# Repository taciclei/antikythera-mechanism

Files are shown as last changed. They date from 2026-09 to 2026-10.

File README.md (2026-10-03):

# Antikythera Mechanism: a functional, verified 3D reconstruction

**English** · [Français](README.fr.md) · [Español](README.es.md) · [Deutsch](README.de.md) · [Italiano](README.it.md) · [Português](README.pt.md) · [Ελληνικά](README.el.md) · [中文](README.zh.md) · [日本語](README.ja.md)



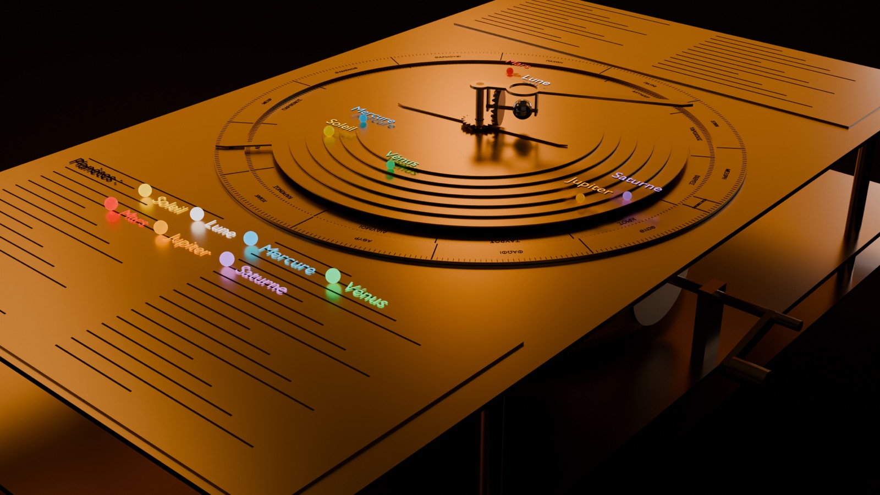
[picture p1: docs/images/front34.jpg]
The reconstructed mechanism, front three-quarter view


https://github.com/user-attachments/assets/c810d3ee-ecfa-46e3-b11d-f919c3ae2cd9

https://github.com/user-attachments/assets/40b1f61b-5fb0-4b54-bd1c-1ba1f423a424

The Antikythera Mechanism is a hand-cranked bronze astronomical calculator built in Greece in the 2nd or 1st century BC and recovered from a shipwreck in 1901. It is the oldest known complex geared machine. This repository contains a complete 3D reconstruction of it in **Blender 5.2**:

- all **69 gears** have their real tooth counts;
- the teeth are conjugate involute teeth, so every pair meshes and actually works;
- every gear train has been **checked in exact fractions** against the astronomical cycle it models;
- the parts have been **checked for collisions** over the whole range of motion.

The whole build was produced in a single pass by Claude Opus 5.5 from one self-contained master prompt ([`PROMPT_OPUS.md`](PROMPT_OPUS.md)), then verified independently.

## Two machines in this repository

| | v1: historical reconstruction | v2: Anticythère 2.0 |
|---|---|---|
| What it is | The ancient machine, as reconstructed by Freeth et al. 2021 | A modern evolution computed with 2026 astronomy |
| Where | Everything at the root of this repository | The [`v2/`](v2/README.md) folder |
| Status | Finished and verified; frozen at the [`v1-historique`](https://github.com/taciclei/antikythera-mechanism/releases/tag/v1-historique) tag | Design study in progress |
| Historical? | Yes; hypothetical parts are marked | **No**: it is an evolution, not a reconstruction |

The rest of this README describes v1.

## Highlights

- **69 gears**, tagged by how certain they are:
  - 30 **surviving**, physically present in the fragments (CT scans);
  - 7 **reconstructed**, from strong evidence;
  - 32 **hypothetical**, from the model of Freeth et al. 2021.

  Each status has its own Blender collection, so each group can be hidden or shown.
- **Exact mathematics.** 1 turn of the main wheel b1 is 1 year. The mechanism has exactly **one degree of freedom** (the crank), and all 22 targets match exactly as fractions (sample below).

  | Output | Exact rate (turns/year) | Cycle |
  |---|---|---|
  | Moon (mean) | 254/19 | 254 sidereal months in 19 years |
  | Metonic dial | −5/19 | 5 turns = 19 years = 235 lunar months |
  | Saros dial | −940/4237 | 4 turns = 223 lunar months |
  | Lunar nodes (Dragon Hand) | −5/93 | 18.6 years, backwards |
  | Venus | 289/462 relative to b1 | 289 synodic periods in 462 years |
- **Formally proved in Lean 4.** [`lean/`](lean/README.md) contains 193 theorems, checked by Lean's kernel with Mathlib, with no `sorry`:
  - the mean-rate kinematics has exactly **one degree of freedom**, and every rate follows from the tooth counts;
  - the 22 targets hold, and so do the Metonic, Saros, Exeligmos, Callippic and Olympiad cycles and the planetary period relations;
  - the 37 centre distances are correct to within 10⁻⁶ mm;
  - the pin-and-slots keep their mean rates, and the lunar anomaly amplitude lies between 6.579° and 6.581°.

  Mutation tests show that Lean rejects a wrong tooth count, a wrong target or a misplaced axis.
- **It works mechanically.**
  - Centre distances are exact to 10⁻⁶ mm, and every contact ratio is ≥ 1.2.
  - There is **0 interpenetration** on thousands of 3D (BVH) samples: every mesh over a tooth pitch, every pin-and-slot cycle, and 168 pairs of parts at 240 crank positions.
- **The Moon speeds up and slows down with round gears**, not oval ones. A pin-and-slot on the rotating e3 turntable reproduces Hipparchus' lunar anomaly (±6.58°).
- **Planets move backwards at the right time.** Mars, Jupiter and Saturn go retrograde at opposition (180° ± 0.03°), and Mercury and Venus stay within their maximum elongations.
- **One crank drives everything.** All motion comes from `AM_Controller["crank"]` in years, through simple-expression drivers, so the file animates without enabling Python scripts.
- **Readable display.** Each of the seven ancient "planets" has its own colour and a label that follows it (Sun, Moon, Mercury, Venus, Mars, Jupiter, Saturn), plus a legend.
- **Museum lighting.** The scene has a dark cyclorama backdrop and warm softboxes, rendered with AgX colour. This setup was chosen from three designs rendered side by side.
- **Exploded view.** Move `AM_Controller["explode"]` from 0 to 1 and every part slides along the stacking axis.
- **3D printing.** One STL per part plus a full 3MF, in three profiles: resin ×1, resin ×1.5 and FDM ×2.

| Front dial | Back dials |
|---|---|
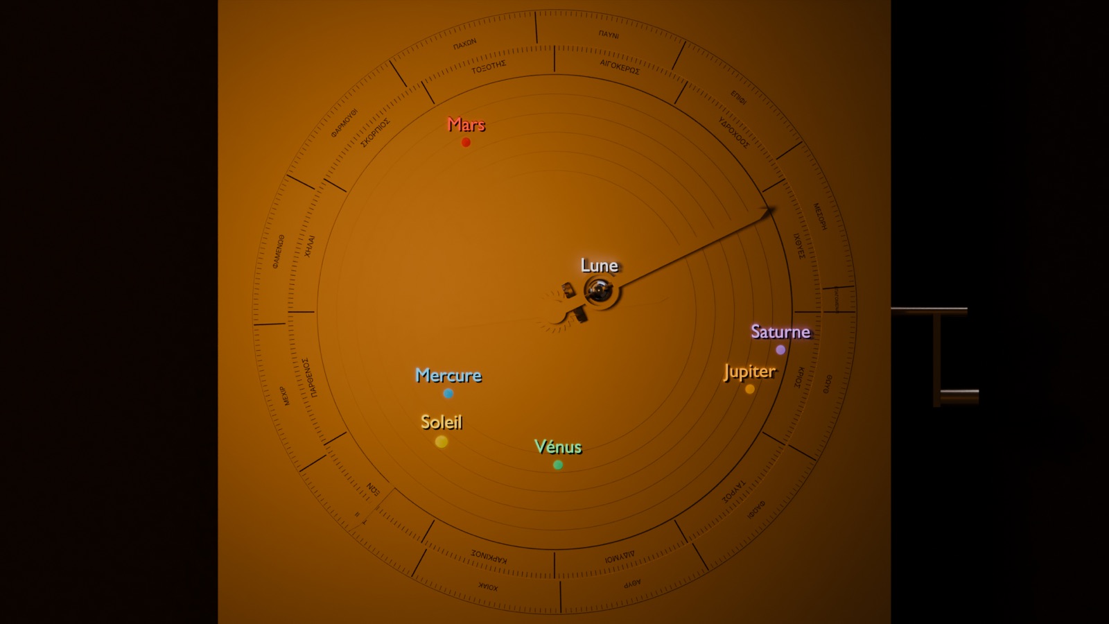
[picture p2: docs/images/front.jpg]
Front dial with coloured, labelled planets
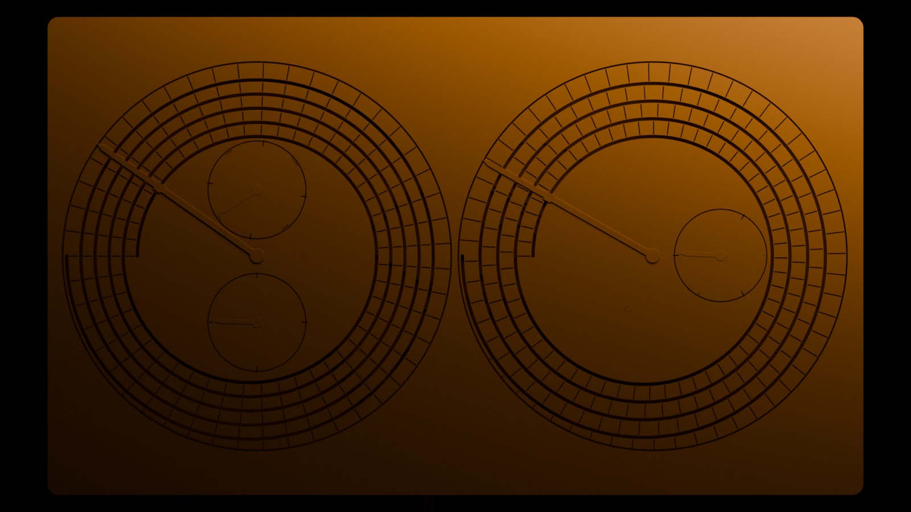
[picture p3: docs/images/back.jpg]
Metonic and Saros spirals
|  |  |

| Exploded view | Inside, opened |
|---|---|
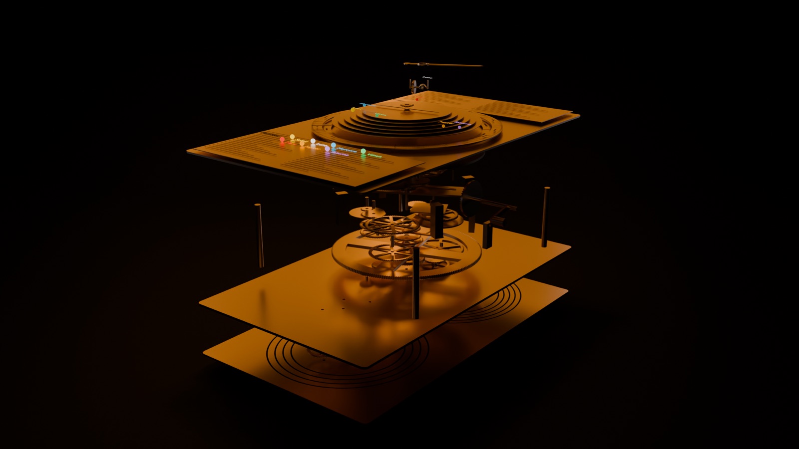
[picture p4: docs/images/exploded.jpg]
Exploded still
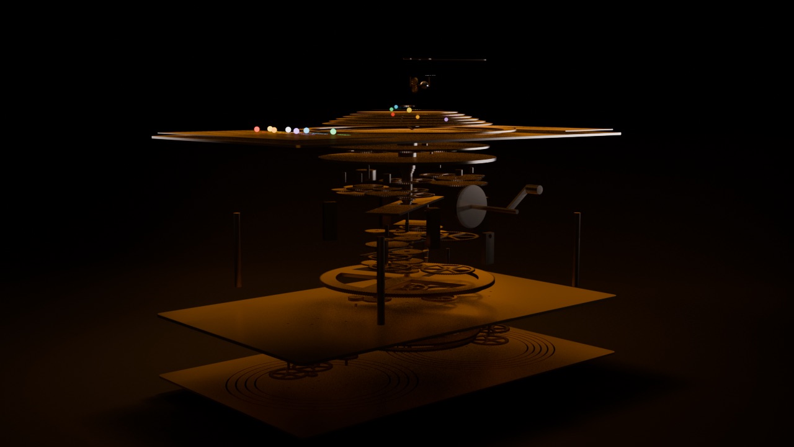
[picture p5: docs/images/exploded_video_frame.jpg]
Frame of the exploded video
|  |  |

## Videos

- [`antikythera.mp4`](build/out/renders/antikythera.mp4): 20 s. The crank turns 4 years, and the planets, Moon and back dials all move.
- [`antikythera_eclate.mp4`](build/out/renders/antikythera_eclate.mp4): 15 s exploded view. The mechanism opens layer by layer while the gears keep turning, then closes again.

Planets that sometimes move **backwards** in the videos are not a bug. This is the **retrograde motion** seen from Earth, and the mechanism was built to show it. The Dragon Hand (the lunar nodes) always turns backwards.

## Learn to read the machine

- **Explainer film** (in French, 2 min 40 s): [*Le ciel dans une boîte : comment lire la machine d'Anticythère*](https://youtu.be/eXvYkouJy_w). Seven chapters take you from the wreck to reading every dial:
  - the crank is time;
  - the Sun, the Moon and its phase on the front;
  - the planets (hypothesis) and their retrograde motion;
  - the 19-year calendar and the Games on the back;
  - how to predict an eclipse;
  - an honest answer about navigation: it was not a navigation instrument, but its star calendar marked the sailing season.
- **Interactive page**: [*Lire la machine*](https://taciclei.github.io/antikythera-mechanism/lire/). Set any date, turn the crank and read every pointer in plain French. It also finds the next full moon, the next eclipse *according to the machine* and the next Games. Calibrated on the real sky at J2000, the machine announces the total solar eclipses of 12 August 2026 and 2 August 2027 to within a few hours.
- **Behind both**: [`tools/explainer/`](tools/explainer/README.md).
  - An astronomy engine that matches the Blender drivers to 6·10⁻⁷ rad.
  - Eclipse glyphs **computed by our model**; they are not copied from the original dial.
  - The film pipeline: timeline tied to the words of the narration, shots, 2D diagrams, compositing.
- **The film's French voice-over** was generated locally with Mistral's Voxtral TTS. Its weights are licensed CC BY-NC 4.0, so the film is shared for non-commercial use.

## Quick start

1. Install **Blender 5.2** or later.
2. Open [`build/out/am.blend`](build/out/am.blend) and press **Space** to play the animation.
3. Select `AM_Controller` and change its custom properties:
   - `crank`: years; 1 is one turn of b1;
   - `explode`: 0 to 1;
   - `patina`: 0 is new bronze, 1 is museum patina.
4. Use the Outliner to hide collections:
   - `AM_CASE` and `AM_DIALS` to see the gearing;
   - `AM_HYPOTHETICAL` to keep only what is attested;
   - `AM_LABELS` to remove the labels;
   - `AM_STAGE` to remove the lighting set.
5. Click any part to read its custom properties: `status`, `role`, `teeth`, `module` and `sources`.

### Re-run the verification

Use the Python bundled with Blender. The paths below are for macOS; adapt them on other systems.

```sh
PY=/Applications/Blender.app/Contents/Resources/5.2/python/bin/python3.13
BL=/Applications/Blender.app/Contents/MacOS/Blender

$PY tools/validate_spec.py          # exact linear solve (1 DOF, 22 targets), centre distances, collision screening
$PY tools/check_kinematics.py       # pin-and-slot laws, followers, elongations, retrogrades, solar apogee
cd build && $PY -m unittest discover -s tests && $PY -m am.verify --stage all && cd ..
$BL -b build/out/am.blend --python-exit-code 1 -P tools/crosscheck_blend.py   # Blender rotations vs an independent solver
```

[`build/README.md`](build/README.md) lists every build, check, export and render step, with one command per step.

### Check the formal proofs (Lean 4)

Install [elan](https://lean-lang.org/install) once, then:

```sh
cd lean
lake exe cache get    # download the compiled Mathlib (about 5 GB)
lake build            # check every proof; warnings are errors, so success means no sorry
cd ..
python3 tools/lean_mutation_test.py   # Lean must reject 9 deliberately wrong mechanisms
```

[`lean/README.md`](lean/README.md) lists what is proved, module by module, and what is not.

### Rebuild everything from the master prompt

In an **empty** folder, with [Claude Code](https://claude.com/claude-code):

```sh
claude -p --model 'claude-opus-5-5[1m]' --effort xhigh --permission-mode acceptEdits \
  --allowedTools Bash Read Write Edit Glob Grep < PROMPT_OPUS.md
```

- [`prompts/PROMPT_OPUS_v1_validated.md`](prompts/PROMPT_OPUS_v1_validated.md) is the exact version that produced this build in one pass (89 min).
- [`PROMPT_OPUS.md`](PROMPT_OPUS.md) is v1.3. v1.2 added the planet colours and labels, the museum staging, the explode slider and the exploded video; v1.3 replaces the Olympiad (Games) dial labels with the historical pairs of festivals, two per year. All of these were added to this build afterwards with the scripts in `tools/`, and v1.3 has not yet been rerun from scratch.

## How it was made

1. **Research.** Parallel agents read the primary sources: Freeth et al. 2006, 2008 and 2021 (with the Supplementary Information), Price 1974, Budiselic et al. 2020, Woan & Bayley 2024, Anastasiou et al. 2014, and others. The results were reconciled into one data set, then checked by a sceptic agent.
2. **Specification.** [`spec/antikythera.json`](spec/antikythera.json) is the single source of truth. It gives the teeth, module, axis position, z range and bore of every gear, and every shaft, stud, boss, pin, dial and material. It is generated by `tools/make_spec.py`, which fixes 22 geometric impossibilities in the published data (for example, b2 cannot mesh with both c1 and l1 at the published distances). Every centre distance is solved exactly.
3. **Independent checks.** `tools/validate_spec.py` and `tools/check_kinematics.py` share no code with the generator, and mutation tests confirm they catch injected errors.
4. **Crown teeth by envelope.** `tools/crown_envelope.py` computes the contrate teeth of a1 and q1 as the region the mating teeth never sweep. `tools/test_crowns_blender.py` then checks them with BVH in Blender.
5. **Adversarial reviews.** Two rounds of independent reviewers covered data, the Blender API tested live, executability and geometry, and found 5 blockers and about 60 other issues. All of them are fixed.
6. **One-pass build** by a fresh Opus 5.5 session from the prompt alone: 131 turns, about 5,000 lines of code, and all acceptance criteria green.
7. **Independent verification** of the result: tests, exact checks, the full BVH check, and a cross-check of every body in `am.blend` against the independent solver (7·10⁻⁷ rad).
8. **Formal proofs.** `tools/make_lean.py` translates the spec into Lean 4. The kinematics, targets and centre distances are proved from it. Hand-written modules add the pin-and-slot analysis and the astronomy, and adversarial reviewers and mutation tests checked that each statement says what it claims.

## Repository layout

```
PROMPT_OPUS.md            master prompt (v1.3), self-contained; embeds the full JSON spec + SHA-256
prompts/                  the prompt version validated by the one-pass build (v1)
spec/antikythera.json     single source of truth (gears, axes, shafts, trains, dials, staging, video)
research/                 raw multi-agent research results with source URLs
tools/                    spec generator, validators, crown envelopes, Lean generator, annotation/staging/explode/render scripts
tools/explainer/          astronomy engine, eclipse glyphs, diagrams, inserts and the explainer-film pipeline
lean/                     Lean 4 + Mathlib proofs: kinematics, targets, centre distances, pin-and-slot, astronomy
build/                    the project generated by the one-pass build (am/, blender_scripts/, tests/, README)
build/out/                am.blend, verification report (report.md/html), checks, print files, renders, videos
docs/                     dossier (HTML), images and the interactive page docs/lire/ (GitHub Pages)
```

## Honest limits

- The planetary trains, the lunar nodes and the true Sun follow the **hypothetical** model of Freeth et al. 2021. A working animation does not prove how the original was built.
- Some quantities are not published. For these the spec uses documented defaults, listed in `spec/antikythera.json` → `unresolved_defaults`:
  - axis angles on the rear plate;
  - cosmos ring radii;
  - starting phases (the epoch is uncalibrated).
- The Lean proofs cover the mean-rate kinematics, the targets, the centre distances and the pin-and-slot and follower laws. Contact ratio, face overlap, undercut and collisions are checked by the Python tools and in Blender, not in Lean.
- The teeth are conjugate involutes (a 30° rack, which is the ancient equilateral-triangle tooth), not the hand-filed triangles of the original.
- Planet colours are for readability only; they are not historical.

## Main sources

- T. Freeth et al., "A Model of the Cosmos in the ancient Greek Antikythera Mechanism", *Scientific Reports* 11, 5821 (2021), with its Supplementary Information.
- T. Freeth et al., "Decoding the ancient Greek astronomical calculator known as the Antikythera Mechanism", *Nature* 444, 587 (2006).
- T. Freeth, A. Jones, J. Steele, Y. Bitsakis, "Calendars with Olympiad display and eclipse prediction on the Antikythera Mechanism", *Nature* 454, 614 (2008).
- T. Freeth & A. Jones, "The Cosmos in the Antikythera Mechanism", ISAW Papers 4 (2012).
- D. de Solla Price, *Gears from the Greeks* (1974).
- C. Budiselic et al. (2020); G. Woan & J. Bayley (2024): calendar ring hole count.
- M. Anastasiou et al. (2014): the back-dial spirals.

The full list with URLs is in `spec/antikythera.json` → `sources`.

## Licence

- **Code**: MIT ([`LICENSE`](LICENSE)).
- **Renders, videos, 3D model, print files and texts**: CC BY 4.0 ([`LICENSE-MEDIA.md`](LICENSE-MEDIA.md)).
- **Explainer film**: its voice-over was generated with Voxtral TTS (weights CC BY-NC 4.0), so the film is for non-commercial use.
- **Scholarly data**: please cite the works above.

---

Built with [Claude Code](https://claude.com/claude-code) (Claude Opus 5 / 5.5) for taciclei.

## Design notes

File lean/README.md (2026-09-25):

# Formal proofs in Lean 4

This folder is a [Lean 4](https://lean-lang.org) project, built on [Mathlib](https://github.com/leanprover-community/mathlib4). Its theorems about the reconstructed Antikythera Mechanism are checked by Lean's kernel. A successful `lake build` means all of the following:

- every theorem is fully proved: warnings are errors, so no `sorry` gets through;
- no theorem uses an axiom beyond Lean's three standard ones (`propext`, `Classical.choice`, `Quot.sound`), which `Antikythera/Audit.lean` checks for every declaration;
- the files generated from the spec are exactly what `tools/make_lean.py` produces. The GitHub workflow regenerates them and compares.

## What is proved

| Module | Content | Theorems |
|---|---|---|
| `Kinematics.lean` (generated) | One equation per gear contact, taken from the tooth counts: 37 Willis equations, 2 crown pairs, 4 pin-and-slots and 3 followers. See the list below the table. | 5 |
| `Targets.lean` (generated) | The spec's 22 astronomical targets, derived from the tooth counts alone. `target_b` is the normalisation, 1 turn of b1 per year. | 22 |
| `Geometry.lean` (generated) | For all 37 external meshes: equal modules, and a centre distance equal to m(z₁ + z₂)/2 within 10⁻⁶ mm. | 37 |
| `PinSlot.lean` | The nonlinear couplings. See the list below the table. | 71 |
| `Astronomy.lean` | The cycles and the precision. See the list below the table. | 58 |
| `Audit.lean` | Fails the build if any declaration depends on `sorryAx` or on a non-standard axiom. | — |

**`Kinematics.lean`** proves four results:
- `determined` and `determined_by_crank`: the crank fixes every mean rate;
- `consistent`: the equations have a solution for every crank speed;
- `moves`: the mechanism can turn;
- `one_dof`: the admissible mean-rate vectors form exactly one line, so the mechanism has **one degree of freedom**.

**`PinSlot.lean`** covers the nonlinear couplings:
- the spec's `atan2` laws for the four pin-and-slots and the three followers;
- the exact maximal deviation `arcsin(e/r)`;
- the smooth, strictly monotone slot motion;
- mean rates unchanged by a bounded lag, which formally justifies the linear fields of `Kinematics`;
- the lunar anomaly amplitude: `6.579° < arcsin(1.1/9.6) < 6.581°`;
- the amplitudes for Saturn, Jupiter, Mars, Mercury, Venus and the true Sun.

**`Astronomy.lean`** covers the cycles and the precision:
- sidereal month 254/19 and Metonic cycle (19 years = 235 synodic months);
- the Saros (223 months = 4 turns), Exeligmos, Callippic (940 months = 76 years) and Olympiad dials;
- lunar anomaly and apsides, and the nodes (Dragon Hand);
- the planetary period relations, where sidereal = solar − synodic;
- the precision in days against modern values, with 1 year = 365.2422 days. For example, the gear-implied sidereal month is within 0.0005 days of 27.321661.

Total: **193 theorems** in about 2,300 lines.

## Scope and limits

- The kinematic theorems are about **mean rates**. The instantaneous nonlinear motion of the pin-and-slots and followers is treated in `PinSlot.lean`.
- The **planetary gearing, the Dragon Hand and the true Sun** follow the hypothetical model of Freeth et al. (2021). Lean proves what that model computes, not that the ancient mechanism was built that way.
- **Not covered by Lean**: contact ratio, face overlap, undercut, crown-gear geometry and collisions. These are checked by `tools/validate_spec.py`, `tools/check_kinematics.py` and the BVH tests in Blender.

## Check it yourself

```sh
# once: install elan (the Lean toolchain manager), see https://lean-lang.org/install
cd lean
lake exe cache get    # download the compiled Mathlib (about 5 GB)
lake build            # check every proof (about 2 minutes)
cd ..
python3 tools/make_lean.py            # regenerate Kinematics / Targets / Geometry from the spec
python3 tools/lean_mutation_test.py   # Lean must reject 9 deliberately wrong mechanisms
```

The mutation test does two kinds of change:
- **In the Lean files**: a tooth count, the sign of a Willis equation, a carrier, a rate, a target value, or an axis moved by 10⁻⁵ mm.
- **In the spec, end to end**: one tooth count on the Metonic train and one on the Olympiad train.

Every mutant must fail to compile. The unmutated control must compile.

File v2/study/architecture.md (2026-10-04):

# Anticythère 2.0 — Architecture de la machine

> ⚠️ **Ce n'est pas une reconstruction historique.** C'est l'architecture d'une machine moderne, dans l'esprit
> d'Anticythère : une boîte, une manivelle, des cadrans. La v1 historique reste à la racine du dépôt.

Ce document dit **où va chaque pièce** et **comment les mouvements circulent** dans la machine. Il est produit par
`v2/tools/architecture.py`. Le script lit `spec/trains.json` et `research/calc/`, place les trains d'engrenages roue
par roue, puis vérifie qu'aucune pièce n'en heurte une autre. Les choix de conception sont dans `tools/arch_layout.py`,
`arch_routes.py` et `arch_faces.py` ; le résultat complet est dans `spec/architecture.json`.

**Version 4.** L'architecture a été relue trois fois par des revues adversariales indépendantes :
- `study/review.md` sur la version 1 ;
- `study/review2.md` sur la version 2 ;
- `study/review3.md` sur la version 3.

Chaque défaut trouvé a été corrigé ; le § 1 dit lesquels et comment.

## 0. L'essentiel

- **Une caisse de 470 × 360 × 391 mm** (largeur × hauteur × profondeur), plus l'orrery d'environ
  70 mm sur le couvercle. Masse estimée : **24,2 kg** en laiton, **20,7 kg**
  avec des platines intérieures en aluminium.
- **Trois faces** : devant le ciel vu de la Terre, derrière le calendrier et les éclipses, dessus le système solaire.
- **Cinq étages**, sept **tours planétaires** et un **bloc de la Lune**.
- **Environ 511 roues dentées**, détaillées au § 7.
- **Vérifié** :
  - 379 pièces modélisées en 3D (cylindres et tringles, avec leur cote z) ;
  - **0 collision** ;
  - 13 trains placés roue par roue ;
  - les 70 arbres de `trains.json` ont tous une place (13
    d'entre eux roue par roue, les autres dans des blocs) ;
  - faces et couvercle conformes.

## 1. Ce qui a changé après les revues

### 1.1 Première revue (version 1 → version 2)

| Défaut relevé (`review.md`) | Réponse de la version 2 |
|---|---|
| B1 · les copies de l'UAK Terre n'avaient pas d'entrée Y | Le bus arrive **sur l'axe** de la tour, sur un tube Y. Un couple 1:1 (ou un couple à pignon fou) reprend Y vers l'entrée du train. Le tube Y monte jusqu'à la copie de l'UAK Terre. |
| B2 · train J → Y : la roue de 144 traversait l'arbre Y | Ordre des couples inversé (10:83, 19:144, 31:180) ; la roue de 180 est sur Y. |
| B3 · pignons du moyeu Y4 superposés | Pignons modélisés ; deux couronnes Y4 sur deux couches (T1, T2). |
| B4 · roues du carrousel percées | Roues de 64 modélisées ; pas régulier de 40° ; tringles d'arrivée vérifiées avec le carrousel. |
| B5 · boîte de Laplace trop petite | Rayon calculé depuis les trains (r ≥ 75,1 mm, plus 4 mm) ; trois trains empilés de 10 mm. |
| I1 · mauvais arbre de précession au bloc du temps | Le bloc reçoit l'arbre de la roue de 131 et le ramène au rapport de l'anneau par son propre couple 15:179. |
| I2 · sens de rotation absent | Tableau des sens (§ 8) : chaque chaîne a un renvoi conique réglable ou un pignon fou. |
| I3 · « jeu nul en marche avant » faux | Faux en effet : onze sorties s'inversent seules. Roues anti-jeu à ciseaux exigées en aval des suiveurs (§ 9). |
| I4 · entrées manquantes (temps, Lune, bras de Lune) | Tringles J et Y vers le bloc du temps, Y vers le bloc Lune, 11ᵉ tringle (Lune) vers le couvercle. |
| I5 · arbres non prolongés | Tout arbre de train va de la platine à un pont et traverse tous les plans de son étage. |
| I6 · couches de tringles trop minces | Coniques m 0,4 (Ø 10,4 mm) et couches de 15 mm. |
| I7 · liens trop larges, interfaces cachées | Liens pièce à pièce seulement ; interfaces listées avec leur profondeur (§ 6). |
| I8 · prise héliocentrique | Couple de prise vers un arbre décalé, puis conique ; palier excentrique du suiveur F décrit (§ 10). |
| I9 · roues oubliées | Les 71 roues internes sont comptées, plus tous les nouveaux renvois. |
| I10 · pignons fous non placés | Placés (Mercure, nœud), dans le couple que choisit la recherche. |
| M1–M10 | Corrigés dans le texte : pile Ø 18,4 mm, jeu recalculé, anneau tropique, couvercle, sens des cadrans arrière, masse sans options. |

Trois choix nouveaux sont apparus pendant la reprise :
- **Neptune et Uranus échangent leurs tours.** Neptune est passée au centre de la rangée du bas.
- **Le couple 10:131 de la précession** est sous la platine P4. L'arbre L de Neptune y descend.
- **Le train du périgée** est à l'étage 4. Son arbre de sortie descend dans le bloc de la Lune.

**Deux couples changent de module ; leurs rapports restent exacts :**
- Neptune, 11:147 en m 0,55 ;
- Jupiter, 10:26 en m 0,7.

Comme dans la v1, c'est la géométrie qui commande ici, pas le rapport.

### 1.2 Seconde revue (version 2 → version 3)

| Défaut relevé (`review2.md`) | Réponse de la version 3 |
|---|---|
| N1 · dans 4 tours, la reprise directe inversait le sens de la planète | Toutes les reprises passent par un **pignon fou** (24 → fou → 24), qui garde le sens. Le fou tourne sur un **tenon porté par le pont** : son arbre ne descend pas jusqu'à la roue finale, ce qui place aussi Vénus et Neptune. |
| N2 · les couples d'entrée du bloc Lune changeaient les rapports | Couples 1:1 dédiés : 100:100 (entraxe 50) pour L et Ω, 72:72 (entraxe 36) pour ϖ. |
| N3 · l'arbre de précession n'atteignait pas le bloc du temps | Coq de 2 mm sous le couple 10:131, puis le plan du couple, puis la tringle au-dessus. Un arbre descend dans le bloc, en un point libre choisi par la recherche. |
| N4 · la bague du suiveur F ne tenait pas avec la prise à 12 mm | La roue de F (46 dents, r 12) tourne sur la bague excentrique ; sa partenaire est à 23 mm. Jupiter, Saturne et Mercure prennent du côté −x. |
| N5 · la hauteur des blocs n'était pas vérifiée | Budget de plans par bloc, vérifié (§ 4). Étage 5 : deux demi-niveaux de 30 mm. Pile avant et boîte de Laplace : 51 mm. |
| N6 · `prec_avant` : tringle de 8 mm | Remplacée par un arbre droit jusqu'au pignon de l'anneau. |
| N7 · arbres de précession sans palier bas | Coq en bas de la couche T2 (N3). |
| N8 · ciseaux sur des coniques de Ø 10 | Coniques précontraintes par ressort axial. Les 9 couples 64:64 ont des ciseaux, et leurs 9 demi-roues sont comptées. |
| N9 · liens par préfixe de nom | Liens par identifiant exact. Seules les parties d'un même axe de tour répondent à son nom. Contrôle strict au § 6. |
| N10 · comptes et interfaces | Roues recomptées ; interfaces complétées (arrivée de Y au bloc Lune). |

### 1.3 Troisième revue (version 3 → version 4)

| Point relevé (`review3.md`) | Réponse de la version 4 |
|---|---|
| A · les couples d'entrée 100:100 et 72:72 du bloc Lune ne trouvaient aucun plan | Entrées L, Ω, ϖ par 40 → pignon fou → 40 (même sens, rapport 1:1), **modélisées et placées** sans collision. |
| B · le budget du bloc Lune oubliait 2 différentiels et le 30:155 | Budget complet : 26 plans (78 mm). Étage 5 : deux demi-niveaux de 39 mm. Laplace : 18 plans (54 mm), pile avant de 54 mm. |
| B · différentiels « plats » contre coniques dans `trains.json` | Choix assumé : différentiels à engrenages droits, même relation, 3 plans de haut. |
| C · rien ne liait l'arbre de précession du bloc du temps à `prec_avant` | La tringle de précession finit sur l'arbre `prec_avant`, qui monte à l'anneau et descend dans le bloc. |
| Textes, compte de la copie de l'UAK Terre du bloc du temps (2 roues), équation du temps | Corrigés ; l'équation du temps est donnée avec l'écart de la copie (§ 11). |
| Roue de prise centrée sur l'axe au lieu de F | Écart de 3,7 mm au plus ; les jeux restent ≥ 3,8 mm (§ 10.3). |

**Un autre choix nouveau : λ du bloc du temps.**
- **Le problème.** La chaîne qui prenait λ sur l'UAK maîtresse (roue, pignon fou de r 30, roue) coupait trois arbres
  du bloc du temps.
- **La solution.** Le bloc a maintenant sa propre copie de l'UAK Terre, menée par Y, comme les tours et le bloc Lune.

## 2. Le principe : une base de temps, deux bus, des tours

1. **La manivelle mène l'arbre-jour J** (1 tour par jour solaire moyen). Le calendrier grégorien impose ce choix.
2. **J mène l'arbre de l'année Y** par 3 couples.
3. **Des bus de tringles distribuent J et Y**, comme les renvois qui mènent les cadrans d'une horloge de clocher :
   - au départ, une couronne de 96 dents mène des pignons de 24, et la tringle tourne 4 fois plus vite ;
   - à l'arrivée, un pignon de 24 mène une couronne de 96 ;
   - le rapport net vaut **1:1 exactement**.
4. **Chaque tour planétaire** reçoit Y sur un tube, dans son axe. Elle empile trois étages :
   - le train moyen, à l'étage 4. Un pignon fou sur tenon reprend Y du tube vers l'entrée du train (24 → fou → 24, même sens), et la roue finale revient sur l'axe, comme dans la minuterie d'une horloge ;
   - l'unité de Kepler de la planète et une copie de celle de la Terre, à l'étage 3 ;
   - le module vectoriel, à l'étage 2.
5. **Vers l'avant**, chaque sortie rejoint la pile de tubes du grand cadran par une tringle et un **carrousel** de neuf arbres, à 40° d'intervalle sur un cercle de 32 mm.

## 3. Les trois faces

### 3.1 Face avant : le ciel vu de la Terre

| Cadran | Centre (mm) | Rayon | Ce qu'il montre |
|---|---|---|---|
| Le ciel vu de la Terre | (0 ; 0) | 150 | Soleil vrai (arbre central) ; Lune vraie et boule de phase ; Mercure ; Vénus ; Mars ; Jupiter ; Saturne ; Uranus ; Neptune ; Dragon (nœuds de la Lune) |
| Horloge 24 h | (−188 ; 118) | 34 | temps solaire moyen (arbre-jour J) ; temps sidéral (gmst) |
| Jupiter et ses lunes | (−188 ; −118) | 34 | Io ; Europe ; Ganymède ; Callisto ; ligne des conjonctions ν ; lunette (barre à λ_J,géo + 90°) |
| Équation du temps (±16,5 min, ×10) | (188 ; −118) | 34 | équation du temps |
| Plaque d'époque (fixe) | (188 ; 118) | 34 | gravé : orbites figées en 2050, valable 2000–2100, date de mise à l'heure |

**Les deux anneaux du grand cadran :**
- **Constellations J2000 (fixe).** C'est le repère des étoiles.
- **Zodiaque tropique et mois grégoriens (tournant).** Il recule d'un tour en 25 772 ans : c'est la précession.

**La commande de l'anneau tropique.** L'anneau est une seule pièce qui tourne dans une feuillure de la platine-cadran.
- Ses 179 dents intérieures (m 0,8) sont à r 71,6 mm, sous les aiguilles.
- Le pignon de 15 dents qui le mène passe par un trou de la platine.
- Il n'y a donc pas de fente annulaire.

**La pile centrale.** Elle compte dix aiguilles : l'arbre du Soleil, au centre, et neuf tubes. Son diamètre est de
18,4 mm, avec un arbre de 4 mm et 1,6 mm de plus par tube.

Les tubes s'empilent de l'arrière vers l'avant. Le Dragon est le plus extérieur, la Lune la plus intérieure.

### 3.2 Face arrière : le temps et les éclipses

| Cadran | Centre (mm, repère machine) | Rayon | Ce qu'il montre |
|---|---|---|---|
| Calendrier grégorien | (−112 ; 15) | 105 | anneau des 366 dates (lu à l'index du haut) ; guichet du jour de la semaine ; cadran des années 00-99 et guichet des 400 ans ; voyant « bissextile » |
| Éclipses | (112 ; 15) | 105 | Soleil vrai ; Lune vraie ; disque des nœuds gravé en γ et en magnitudes ; index de la coulisse (γ, amplifié) ; secteur total / annulaire |
| Saros (223 lunaisons) et Exeligmos | (170 ; −128) | 40 | aiguille du Saros sur 223 cases ; petit cadran de l'Exeligmos (+0 h, +8 h, +16 h) |
| Plaque « mode d'emploi » (fixe) | (−120 ; −135) | 30 | gravé : comment lire chaque cadran, comme les inscriptions de la v1 |

**Le sens des graduations.** La face arrière se lit de dos. Un arbre qui tourne dans le sens horaire vu de face tourne
donc dans le sens anti-horaire vu de dos. Les graduations sont gravées pour le lecteur de dos :
- l'anneau des dates avance dans le sens anti-horaire vu de dos ;
- le Saros et les éclipses suivent la même règle.

### 3.3 Couvercle : le système solaire vu d'en haut

| Corps | Rayon affiché (mm) | Source de l'angle |
|---|---|---|
| Mercure | 24 | tour de Mercure (suiveur F) |
| Vénus | 38 | tour de Vénus (suiveur F) |
| Terre | 52 | UAK maîtresse |
| Mars | 66 | tour de Mars (suiveur F) |
| Jupiter | 80 | tour de Jupiter (suiveur F) |
| Saturne | 92 | tour de Saturne (suiveur F) |
| Uranus | 102 | tour d'Uranus (suiveur F) |
| Neptune | 111 | tour de Neptune (suiveur F) |

**Ce que montre le couvercle :**
- **Les angles sont exacts.** Ils viennent des mêmes arbres que les aiguilles de devant.
- **Les orbites se voient.** Chaque planète glisse dans une rainure fixe, cercle décentré ou ellipse.
- **Les bras sont à des hauteurs différentes.** Le bras de la Lune (12 mm autour de la Terre) passe au-dessus de la rainure de Mars ; Saturne, Uranus et Neptune ne sont qu'à 3,6–3,8 mm l'une de l'autre.
- **La Terre est un tellurion :** un globe de 14 mm, incliné de 23,44°, qui tourne en un jour sidéral.
- **Le bras de la Lune** est mené par la 11ᵉ tringle.
- **L'aiguille d'ombre** est décalée de γ par la coulisse d'éclipse.

**Les tringles qui montent :** onze, espacées d'au moins 14,0 mm, alors qu'il en faut
12,2 pour leurs pignons.

## 4. L'intérieur : cinq étages

| Étage | Rôle | z (mm) | Sous-étages (z) | Contenu |
|---|---|---|---|---|
| **E5** | étage du temps, du calendrier et de la Lune | 3–123 | anneau 3–9, m1 9–48, m2 48–87, ponts 87–90, T1 90–105, T2 105–123 | cal_anneau, cal_meca, semaine, annees, lune, croix, jour, temps, precession_ring, saros, moon_node, moon_L |
| **E4** | étage des trains moyens (bus de l'année) | 125–185 | A 125–134, B 134–143, C 143–152, ponts 152–155, T1 155–170, T2 170–185 | Y, venus_L, neptune_L, mercury_L, mars_L, uranus_L, saturn_L, jupiter_L, moon_perigee |
| **E3** | étage de Kepler (unités d'anomalie) | 187–219 | uak 187–204, T1 204–219 | 7 tours, terre_maitre |
| **E2** | étage des modules géocentriques | 221–249 | mod 221–249 | 7 tours |
| **E1** | étage des renvois avant | 251–335 | T1 251–266, T2 266–281, pile 281–335 | pile, laplace, horloge, edt, prec_pignon |

**Règles de construction :**
- **Platines.** Des platines de 2 mm séparent les étages.
- **Arbres.** Un arbre de train va de la platine (en E5, d'un pont bas) jusqu'à un **pont** de 3 mm. Il traverse donc
  tous les plans de son étage.
- **Plans.** Chaque couple occupe un plan de 3 mm.
- **Tringles.** Leurs couches font 15 mm. Deux tringles d'une même couche ne se croisent jamais.

**Budget en hauteur des blocs** (plans de 3 mm, revue N5) :

| Bloc | Plans | Besoin (mm) | Hauteur (mm) | Contenu estimé |
|---|---|---|---|---|
| lune | 26 | 78 | 78 | 4 entrées sur l'axe M (L, ϖ, Ω, Y), copie de l'UAK Terre (4), cascade (13 : réduction 2, équation annuelle = différentiel plat 3 + couple 30:155, évection = différentiel plat 3, anomalie 2, variation 2), prises (3), coulisse d'éclipse et porte-nœuds (2) |
| temps | 20 | 60 | 78 | 5 différentiels plats (2 par plan de 3), joint de Hooke (5 plans), 120:12, 15:179 et son fou, copie de l'UAK Terre (4 plans), entrées et sorties |
| laplace | 18 | 54 | 54 | 3 trains de 3 couples (9), 2 doubleurs, 2 différentiels plats côte à côte (3), 4 couples vers le cadran jovien (4) |
| cal_meca | 8 | 24 | 78 | 2 croix de Malte, différentiel, 20:61, roues-programmes 4/100/400 et cames |

**Blocs-mécanismes** (enveloppes estimées ; leur intérieur sera dessiné en 3D) :

| Bloc | Étage | Centre | Rayon (mm) | Rôle |
|---|---|---|---|---|
| cal_anneau | E5 | (−112 ; 15) | 96,0 | anneau des dates : 200 dents intérieures (m 0,9), 366 crans à sautoir |
| cal_meca | E5 | (−112 ; 15) | 46,0 | croix de Malte (principale et de saut), différentiel, roues-programmes 4/100/400, cames |
| semaine | E5 | (−64 ; −10) | 20,0 | disque des 7 jours, vu par un guichet du cadran du calendrier |
| annees | E5 | (−125 ; −40) | 24,0 | disque du siècle (00-99) et guichet des 400 ans |
| lune | E5 | (112 ; 15) | 50,0 | cascade lunaire à 5 étages sur l'axe M, coulisse d'éclipse sur le porte-nœuds coaxial, copie de l'UAK Terre ; 3 couples d'entrée ramènent L, ϖ, Ω sur l'axe, 4 couples de prise en sortent |
| croix | E5 | (−66 ; −11) | 12,0 | croix de Malte du calendrier, menée par la goupille de J (interface J → calendrier) |
| jour | E5 | (−50 ; −20) | 17,0 | arbre-jour J ; sa goupille mène la croix de Malte du calendrier (6 fentes) et une croix de semaine à 7 positions (même rapport 1:7 que 10:70) |
| temps | E5 | (0 ; −78) | 46,0 | différentiels du temps sidéral, joint de Hooke (ε = 23,44°), équation du temps ×10, couple 15:179 (m 0,4) qui ramène l'arbre de précession au rapport de l'anneau, copie de l'UAK Terre menée par Y (Soleil vrai λ) |
| terre_maitre | E3 | (0 ; 0) | 28,0 | UAK maîtresse de la Terre : Soleil vrai (aiguille, orrery, temps) |
| pile | E1 | (0 ; 0) | 9,2 | pile centrale : arbre du Soleil et 9 tubes coaxiaux (Ø 18,4 mm) |
| laplace | E1 | (−143 ; −88) | 79,1 | boîte de Laplace : trains G, ν, C empilés (10 mm chacun), deux doubleurs, deux différentiels |
| horloge | E1 | (−188 ; 118) | 20,0 | renvoi des aiguilles 24 h : temps moyen (J) et temps sidéral |
| edt | E1 | (188 ; −118) | 14,0 | renvoi de l'aiguille de l'équation du temps |
| prec_pignon | E1 | (0 ; −66) | 8,0 | pignon de 15 dents (m 0,8) qui mène l'anneau tropique (179 dents intérieures) |

## 5. Les tours et les trains, roue par roue

| Planète | Axe (mm) | Module R | Unité de Kepler | Couples (ordre retenu) | Sous-étage | Reprise de Y | Moyeu |
|---|---|---|---|---|---|---|---|
| Mercure | (157 ; 102) | 60 | résolveur de Kepler + ellipse à deux bras | 73:79 · 64:31 · 37:17 | AB | 24 → fou 24 (tenon) → 24 | Y4a |
| Vénus | (−147 ; 92) | 70 | équant bissecté | 124:67 · 166:189 | A | 24 → fou 96 (tenon) → 24 | Y4a |
| Mars | (5 ; 92) | 70 | équant + épicyclet | 97:88 · 41:85 | B | 24 → fou 64 (tenon) → 24 | Y4b |
| Jupiter | (−168 ; −112) | 50 | équant bissecté | 10:26 · 16:73 | A | 24 → fou 32 (tenon) → 24 | Y4a |
| Saturne | (−56 ; −112) | 50 | équant bissecté | 10:41 · 11:79 | A | 24 → fou 32 (tenon) → 24 | Y4b |
| Uranus | (168 ; −112) | 50 | équant bissecté | 10:84 · 10:100 | A | 24 → fou 64 (tenon) → 24 | Y4b |
| Neptune | (56 ; −112) | 50 | équant bissecté | 12:148 · 11:147 | B | 24 → fou 96 (tenon) → 24 | Y4a |

**La recherche.** Pour chaque train, le script essaie toutes les combinaisons suivantes :
- les ordres des couples (le produit ne change pas) ;
- les places du pignon fou ;
- les reprises de Y par pignon fou sur tenon, de 16 à 112 dents (le sens est gardé) ;
- les sous-étages ;
- les angles, de 10° en 10°, avec un élagage dès qu'un arbre viole une règle.

**Les règles :**
- une roue ne touche aucun arbre, sauf le sien et celui de la roue qu'elle mène ;
- deux roues d'un même plan ne se touchent que si elles engrènent ;
- un petit pignon est taillé dans son arbre : sa partenaire peut donc en approcher l'arbre jusqu'au fond de dent.

| Train | Étage / sous-étage | Moyeu | Arbres (entrée → sortie) |
|---|---|---|---|
| `Y` | E4 / A | — | (−50 ; −20) → (−50 ; 3) → (−34 ; 41) → (0 ; 0) |
| `venus_L` | E4 / A | Y4a | (−100 ; 68) → (−58 ; 92) → (−147 ; 92) → (−130 ; 68) |
| `precession_ring` | E5 / T2 (coq + plan + tringle) | — | (56 ; −112) → (91 ; −106) |
| `neptune_L` | E4 / B | Y4a | (92 ; −65) → (99 ; −104) → (56 ; −112) → (70 ; −85) |
| `mercury_L` | E4 / AB | Y4a | (145 ; 82) → (184 ; 97) → (166 ; 112) → (157 ; 102) → (168 ; 78) → (148 ; 94) |
| `mars_L` | E4 / B | Y4b | (37 ; 117) → (29 ; 72) → (5 ; 92) → (26 ; 98) |
| `uranus_L` | E4 / A | Y4b | (134 ; −125) → (142 ; −103) → (168 ; −112) → (155 ; −130) |
| `saturn_L` | E4 / A | Y4b | (−65 ; −88) → (−52 ; −90) → (−56 ; −112) → (−65 ; −102) |
| `jupiter_L` | E4 / A | Y4a | (−194 ; −112) → (−187 ; −101) → (−168 ; −112) → (−181 ; −118) |
| `moon_perigee` | E4 / A | Y4b | (48 ; 10) → (48 ; −22) → (81 ; −3) |
| `saros` | E5 / m1 | Y5 | (154 ; −84) → (159 ; −98) → (170 ; −128) |
| `moon_node` | E5 / m1 | Y5 | (11 ; 46) → (33 ; 38) → (65 ; 32) → (18 ; 40) |
| `moon_L` | E5 / m1 | J5 | (14 ; −21) → (22 ; −18) → (42 ; −10) → (65 ; −2) |

## 6. Renvois et interfaces

| Renvoi | Rôle | Parcours |
|---|---|---|
| `geo_mercury` | longitude géocentrique de Mercure vers la pile avant | arbre à (157 ; 102), E2 mod → E1 T1 ; tringle (157 ; 102) → carrousel (E1 T1) |
| `orr_mercury` | longitude héliocentrique de Mercure vers l'orrery (suiveur F) | tringle prise → haut (E3 T1) |
| `geo_venus` | longitude géocentrique de Vénus vers la pile avant | arbre à (−147 ; 92), E2 mod → E1 T1 ; tringle (−147 ; 92) → carrousel (E1 T1) |
| `orr_venus` | longitude héliocentrique de Vénus vers l'orrery (suiveur F) | tringle prise → haut (E3 T1) |
| `geo_mars` | longitude géocentrique de Mars vers la pile avant | arbre à (5 ; 92), E2 mod → E1 T1 ; tringle (5 ; 92) → carrousel (E1 T1) |
| `orr_mars` | longitude héliocentrique de Mars vers l'orrery (suiveur F) | tringle prise → haut (E3 T1) |
| `geo_jupiter` | longitude géocentrique de Jupiter vers la pile avant | arbre à (−168 ; −112), E2 mod → E1 T1 ; tringle (−168 ; −112) → carrousel (E1 T1) |
| `orr_jupiter` | longitude héliocentrique de Jupiter vers l'orrery (suiveur F) | tringle prise → haut (E3 T1) |
| `geo_saturn` | longitude géocentrique de Saturne vers la pile avant | arbre à (−56 ; −112), E2 mod → E1 T1 ; tringle (−56 ; −112) → carrousel (E1 T1) |
| `orr_saturn` | longitude héliocentrique de Saturne vers l'orrery (suiveur F) | tringle prise → haut (E3 T1) |
| `geo_uranus` | longitude géocentrique d'Uranus vers la pile avant | arbre à (168 ; −112), E2 mod → E1 T1 ; tringle (168 ; −112) → carrousel (E1 T1) |
| `orr_uranus` | longitude héliocentrique d'Uranus vers l'orrery (suiveur F) | tringle prise → haut (E3 T1) |
| `geo_neptune` | longitude géocentrique de Neptune vers la pile avant | arbre à (56 ; −112), E2 mod → E1 T1 ; tringle (56 ; −112) → carrousel (E1 T1) |
| `orr_neptune` | longitude héliocentrique de Neptune vers l'orrery (suiveur F) | tringle prise → haut (E3 T1) |
| `orr_earth` | Soleil vrai (Terre) vers l'orrery | tringle prise → haut (E3 T1) |
| `moon_true` | Lune vraie vers la pile avant | arbre à (132 ; 15), E5 meca → E1 T1 ; tringle (132 ; 15) → carrousel (E1 T1) |
| `node` | nœud ascendant (aiguille du Dragon) vers la pile avant | arbre à (150 ; −5), E5 meca → E1 T1 ; tringle (150 ; −5) → carrousel (E1 T1) |
| `gamma` | course de la coulisse d'éclipse (γ) vers l'aiguille d'ombre du globe | arbre à (118 ; 40), E5 meca → E3 T1 ; tringle (118 ; 40) → (118 ; 168) (E3 T1) |
| `orr_moon` | Lune vraie vers le bras de la Lune du tellurion | arbre à (100 ; 30), E5 meca → E3 T1 ; tringle (100 ; 30) → (100 ; 168) (E3 T1) |
| `lune_Y` | année Y vers le bloc de la Lune (évection, équation annuelle) | tringle hub → (100 ; 62) (E5 T1) ; arbre à (100 ; 62), E5 T1 → E5 meca |
| `j_avant` | arbre-jour vers la boîte de Laplace | tringle hub → (−95 ; −45) (E5 T2) ; arbre à (−95 ; −45), E5 T2 → E1 pile |
| `vers_horloge` | temps moyen (J) et temps sidéral, coaxiaux, vers l'horloge 24 h | arbre à (−21 ; −58), E5 meca → E1 T2 ; tringle (−21 ; −58) → (−188 ; 118) (E1 T2) |
| `vers_edt` | équation du temps (×10) vers son cadran | arbre à (15 ; −58), E5 meca → E1 T2 ; tringle (15 ; −58) → (188 ; −118) (E1 T2) |
| `prec_avant` | arbre de la roue de 131 (précession × 179/15) : il monte droit jusqu'au pignon de l'anneau tropique | arbre à (0 ; −66), E5 meca → E1 pile |
| `tellurion` | temps sidéral vers la rotation du globe de l'orrery | arbre à (−30 ; −92), E5 meca → E3 T1 ; tringle (−30 ; −92) → (−30 ; 168) (E3 T1) |
| `lunette` | longitude géocentrique de Jupiter vers la lunette | arbre à (−168 ; −112), E1 T1 → E1 T2 ; tringle (−168 ; −112) → (−188 ; −118) (E1 T2) |
| `manivelle` | manivelle (paroi gauche) vers l'arbre-jour | tringle (−225 ; 25) → hub (E5 T2) |
| `temps_J` | arbre-jour vers le bloc du temps (temps sidéral, horloge) | tringle hub → (−42 ; −70) (E5 T2) ; arbre à (−42 ; −70), E5 T2 → E5 meca |
| `temps_Y` | année Y vers le bloc du temps (Soleil moyen, précession) | tringle hub → (30 ; −88) (E5 T1) ; arbre à (30 ; −88), E5 T1 → E5 meca |

**Carrousel** (angle de chaque arbre intermédiaire) : Lune 36°, Mercure 76°, Mars 116°, Vénus 156°, Jupiter −164°, Saturne −124°, Neptune −84°, Uranus −44°, Dragon −4°.

**Interfaces déclarées** (une pièce qui entre volontairement dans l'enveloppe d'un bloc) :

| Pièce | Bloc | Entre de (mm) |
|---|---|---|
| `croix` | jour | 11,0 |
| `croix` | cal_meca | 4,9 |
| `lune_Y#z1` | lune | 3,5 |
| `moon_perigee#a2` | lune | 4,0 |
| `moon_node#a2` | lune | 2,0 |
| `moon_node#w4` | lune | 27,7 |
| `moon_L#a3` | lune | 2,0 |
| `moon_L#w5` | lune | 19,2 |
| `lune_entree_moon_L#w1` | lune | 10,5 |
| `lune_entree_moon_L#fou` | lune | 33,0 |
| `lune_entree_moon_L#w2` | lune | 21,0 |
| `lune_entree_moon_node#w1` | lune | 10,5 |
| `lune_entree_moon_node#fou` | lune | 40,5 |
| `lune_entree_moon_node#w2` | lune | 21,0 |
| `lune_entree_moon_perigee#w1` | lune | 21,0 |
| `lune_entree_moon_perigee#fou` | lune | 21,0 |
| `lune_entree_moon_perigee#w2` | lune | 21,0 |

Ce sont :
- la croix de Malte, entre l'arbre-jour et le calendrier ;
- les arbres d'arrivée des trains de la Lune et leurs couples d'entrée (40 → pignon fou → 40), qui ramènent L, ϖ et Ω
  sur l'axe M du bloc ;
- l'arrivée de Y au bloc Lune.

L'intérieur des blocs devra les accueillir.

**Contrôle strict (revue N9).** Le recontrôle compte comme liées les seules pièces citées par leur identifiant exact.
Il trouve 37 recouvrements de plus, tous voulus : une pièce montée sur son propre axe de tour (UAK, tube Y, roue de
prise, couronne du bus, roue finale) ou le pignon de 10 taillé dans l'arbre de Neptune. Aucun recouvrement réel caché.

## 7. Les roues

| Poste | Roues |
|---|---|
| trains, différentiels et pas à pas de trains.json | 196 |
| couronnes des 4 moyeux (96 dents) | 4 |
| tringles de bus vers 11 trains (pignon 24, pignon 24, couronne 96) | 33 |
| reprises 1:1 du tube Y dans les 7 tours (couple, ou couple et pignon fou) | 21 |
| renvoi geo_mercury | 6 |
| renvoi orr_mercury | 6 |
| renvoi geo_venus | 6 |
| renvoi orr_venus | 6 |
| renvoi geo_mars | 6 |
| renvoi orr_mars | 6 |
| renvoi geo_jupiter | 6 |
| renvoi orr_jupiter | 6 |
| renvoi geo_saturn | 6 |
| renvoi orr_saturn | 6 |
| renvoi geo_uranus | 6 |
| renvoi orr_uranus | 6 |
| renvoi geo_neptune | 6 |
| renvoi orr_neptune | 6 |
| renvoi orr_earth | 6 |
| renvoi moon_true | 8 |
| renvoi node | 8 |
| renvoi gamma | 8 |
| renvoi orr_moon | 8 |
| renvoi lune_Y | 5 |
| renvoi j_avant | 3 |
| renvoi vers_horloge | 8 |
| renvoi vers_edt | 4 |
| renvoi prec_avant | 0 |
| renvoi tellurion | 6 |
| renvoi lunette | 4 |
| renvoi manivelle | 1 |
| renvoi temps_J | 3 |
| renvoi temps_Y | 3 |
| renvoi prec_bas (2 couples coniques) | 4 |
| entrées du bloc Lune : 3 couples 40 → fou → 40 (L, Ω, ϖ) | 9 |
| modules vectoriels : 7 × (bras planète 2 + bras Terre 2 + chaîne 1:1 3) | 49 |
| cascade lunaire : 6 couples relatifs | 12 |
| couronne de phase de la Lune (48:48) | 2 |
| cadran jovien : 4 couples | 8 |
| demi-roues anti-jeu (ciseaux) des 9 couples 64:64 du carrousel | 9 |
| bloc du temps : couple 15:179 de la précession + pignon fou | 3 |
| bloc du temps : copie de l'UAK Terre (couple d'entrée) | 2 |
| **Total** | **511** |

**Règles de compte :**
- une tringle 1:1 a deux couples coniques, soit 4 roues ;
- une tringle de moyeu a 3 roues : un pignon au départ, un pignon et une couronne à l'arrivée ;
- chaque tube de la pile ajoute un couple 64:64 ;
- une tringle vers le couvercle compte sa prise, son renvoi d'angle en haut et son couple vers le tube de l'orrery,
  moins le couple conique déjà compté dans `trains.json`.

## 8. Le sens de rotation

**Les règles d'inversion :**
- un couple extérieur inverse le sens, un couple intérieur le garde ;
- un pignon fou inverse ;
- un renvoi conique (ou une couronne) peut faire l'un ou l'autre : cela dépend de la face où engrène le pignon.

Chaque chaîne de renvoi contient au moins un renvoi conique ou un pignon fou. Le sens de chaque arbre peut donc
toujours être réglé pour retrouver le sens `phys` de `trains.json`. Le contrôle sur pièces réelles se fera en 3D.

| Renvoi | Chaîne | Sens sans réglage | Réglage |
|---|---|---|---|
| `geo_mercury` | con → con → ext | − | côté d'engrènement d'une conique |
| `orr_mercury` | ext → con → con → ext | + | côté d'engrènement d'une conique |
| `geo_venus` | con → con → ext | − | côté d'engrènement d'une conique |
| `orr_venus` | ext → con → con → ext | + | côté d'engrènement d'une conique |
| `geo_mars` | con → con → ext | − | côté d'engrènement d'une conique |
| `orr_mars` | ext → con → con → ext | + | côté d'engrènement d'une conique |
| `geo_jupiter` | con → con → ext | − | côté d'engrènement d'une conique |
| `orr_jupiter` | ext → con → con → ext | + | côté d'engrènement d'une conique |
| `geo_saturn` | con → con → ext | − | côté d'engrènement d'une conique |
| `orr_saturn` | ext → con → con → ext | + | côté d'engrènement d'une conique |
| `geo_uranus` | con → con → ext | − | côté d'engrènement d'une conique |
| `orr_uranus` | ext → con → con → ext | + | côté d'engrènement d'une conique |
| `geo_neptune` | con → con → ext | − | côté d'engrènement d'une conique |
| `orr_neptune` | ext → con → con → ext | + | côté d'engrènement d'une conique |
| `orr_earth` | ext → con → con → ext | + | côté d'engrènement d'une conique |
| `moon_true` | ext → con → con → ext | + | côté d'engrènement d'une conique |
| `node` | ext → con → con → ext | + | côté d'engrènement d'une conique |
| `gamma` | crémaillère → con → con | + | côté d'engrènement d'une conique |
| `orr_moon` | ext → con → con → ext | + | côté d'engrènement d'une conique |
| `lune_Y` | con → con → ext | − | côté d'engrènement d'une conique |
| `j_avant` | con → con | + | côté d'engrènement d'une conique |
| `vers_horloge` | con → con | + | côté d'engrènement d'une conique |
| `vers_edt` | con → con | + | côté d'engrènement d'une conique |
| `prec_avant` | int | + | aucun (même sens) |
| `tellurion` | ext → con → con | − | côté d'engrènement d'une conique |
| `lunette` | con → con | + | côté d'engrènement d'une conique |
| `manivelle` | con | + | côté d'engrènement d'une conique |
| `temps_J` | con → con | + | côté d'engrènement d'une conique |
| `temps_Y` | con → con | + | côté d'engrènement d'une conique |
| `prec_bas` | con → con | + | côté d'engrènement d'une conique |
| `reprises de Y dans les tours` | 24 → fou → 24 (2 engrènements) | + | aucun : la reprise par pignon fou garde le sens, la planète et la copie de la Terre tournent comme dans trains.json |
| `entrées du bloc Lune (L, Ω, ϖ)` | 40 → fou → 40 (2 engrènements) | + | aucun : le sens est gardé |

## 9. Le jeu des engrenages

**Le problème.** Avec un jeu de 0,03 mm par paire de dents, les renvois en aval d'un
suiveur laissent **0,82°** de flottement à l'aiguille. Ces renvois sont deux couples coniques
m 0,4 et le couple 64:64.

**Quand ce jeu apparaît.** Il apparaît **chaque fois que la sortie change de sens**, même si la manivelle tourne
toujours dans le même sens. C'est le cas :

- 7 aiguilles planétaires (stations de rétrogradation) ;
- équation du temps ;
- lunette de Jupiter ;
- coulisse d'éclipse γ ;
- aiguille d'ombre ;

C'est plus que l'erreur géométrique, au moment le plus intéressant : la boucle de rétrogradation.

**Le remède retenu** : coniques précontraintes par un ressort axial (le pignon est poussé dans la denture) et couples 64:64 à ciseaux (une demi-roue de plus par tube) ; jeu résiduel ≈ 0.

Un frein à friction ne convient pas : il retiendrait l'aiguille pendant que le jeu se rattrape. Les embrayages à
friction ne servent qu'à la mise à l'heure initiale.

## 10. Bilans

### 10.1 Masse

| Poste | Masse (g) |
|---|---|
| roues des trains (trains.json, sans les options) | 1659 |
| roues des différentiels | 458 |
| roues de renvoi et roues internes (architecture) | 1498 |
| platines intérieures (laiton, ajourées 50 %) | 5184 |
| platines-cadrans avant et arrière (laiton 3 mm) | 6609 |
| caisse en chêne 6 mm et porte arrière | 3437 |
| verre avant 2 mm | 846 |
| arbres, tubes, ponts, goupilles, ressorts | 1800 |
| UAK, modules, cascade, coulisses | 1500 |
| orrery et tellurion | 1200 |
| **Total** | **24,2 kg** |

Avec des platines intérieures en aluminium, la masse descend à **20,7 kg**. Les options
(`gmst_direct`, `synodic`, `saros_223`, `mars_apsides`) ne sont pas comptées.

### 10.2 Manivelle

**Mode normal.** Un pignon de 24 dents engrène la couronne de 96 de l'arbre-jour : **1 tour de manivelle = 6 heures**.

**Mode rapide.** Une boîte 1:30 sur la paroi donne **1 tour = 7,5 jours**. La manivelle « de la semaine » de
`trains.md` n'est plus possible : une croix de Malte ne se mène pas à l'envers.

**Effort.** L'effort de manivelle se mesurera sur prototype.

### 10.3 Fabrication

- **Modules.**
  - Trains : m 0,5, avec deux couples en m 0,55 et m 0,7.
  - Couronnes intérieures : m 0,8 et m 0,9.
  - Renvois coniques : m 0,4. Les coniques 40:40 de `trains.json` vers l'orrery deviennent un couple de prise et une
    conique m 0,4, au même rapport.
- **Tolérance de position :** 0,02 mm.
- **Le suiveur F des planètes extérieures** pivote à 0,4–3,7 mm de l'axe de la tour, à l'intérieur de son rayon. Il
  tourne donc sur une **bague excentrique de Ø 18 mm** fixée à la platine P2, autour de l'axe.
  - Sa roue de prise (46 dents, r 12) est enfilée sur la bague.
  - Elle engrène, à 23 mm, l'arbre décalé qui porte la conique.
  - Mercure, Jupiter et Saturne prennent du côté −x, les autres du côté +x.
  - Le modèle centre cette roue sur l'axe ; en réalité, elle tourne autour de F, jusqu'à 3,7 mm plus loin. Les jeux
    restent d'au moins 3,8 mm.
- **Différentiels** : à engrenages droits (satellites par paires), même relation que les différentiels coniques de
  `trains.json`, mais 3 plans de haut.
- **Les excentriques les plus fins :**
  - l'épicyclet de Mars (0,087 mm) ;
  - le bras Soleil de Neptune (1,6 mm).

  Ils se font par bague excentrique réglable ou par électroérosion.

## 11. Budget d'erreur attendu (2000–2100)

| Aiguille | Géométrie | Physique hors Kepler | Tolérance 0,02 mm | Rapport (°/siècle) |
|---|---|---|---|---|
| Mercure | 0,26° | 15″ | 0,05° | −0,0082° |
| Vénus | 0,21° | 20″ | 0,11° | −0,0009° |
| Mars | 0,24° | 40″ | 0,12° | 0,0060° |
| Jupiter | 0,07° | 0,11° | 0,04° | −0,0022° |
| Saturne | 0,08° | 0,17° | 0,03° | 0,0040° |
| Uranus | 0,05° | 50″ | 0,03° | 0,0052° |
| Neptune | 0,02° | 10″ | 0,03° | −0,0089° |

- **Copies de l'UAK Terre** (tours, bloc Lune, bloc du temps) : une tolérance de 0,02 mm donne environ
  0,05° d'écart entre le Soleil de l'aiguille et celui de chaque copie. Cet écart s'ajoute
  aux colonnes ci-dessus. Pour l'équation du temps, il fait au plus 12 s d'écart avec
  l'aiguille du Soleil.
- **Lune** : 0,26° au maximum, 0,10° rms.
- **Calendrier** : exact de 1582 à 6000 (0 erreur).
- **Temps sidéral** : −0,063 s par siècle.
- **Équation du temps** : 3,1 s au plus pour le modèle. Le bloc du temps
  calcule λ avec sa propre copie de l'UAK Terre : sa tolérance ajoute jusqu'à 12 s, soit
  environ 15 s au pire.
- **Éclipses** : 449 sur 452, erreur sur γ d'au plus 0,035.
- **Jeu** : environ 0 avec les roues à ciseaux ; sinon 0,82° à chaque changement de sens.

## 12. Ce que cette architecture ne prouve pas encore

- **Les blocs restent des enveloppes estimées**, pas des pièces : cascade lunaire, calendrier, temps, Laplace, UAK,
  modules. Leur intérieur, y compris les interfaces du § 6, sera dessiné et vérifié en 3D.
- **Le socle de l'orrery** n'est vérifié que pour l'espacement des tringles qui y arrivent.
- **La dynamique n'est pas calculée :** efforts, frottements, flexion.
- **Le modèle est fait de disques.** Une roue est un disque plein (tête de dent) ; une conique couchée est un disque
  dans sa couche. Les profils de dents et l'interférence fine viendront avec la 3D (BVH, comme la v1).

## 13. Suite

1. Construction 3D dans Blender à partir de `spec/architecture.json`, avec contrôle d'interférence pièce par pièce.
2. Preuves Lean 4 des rapports de `trains.json` et des identités exactes : Laplace, Hooke, calendrier.

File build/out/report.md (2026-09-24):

# Antikythera Mechanism - functional reconstruction: verification report

Spec `Antikythera Mechanism — functional reconstruction spec` v1.0.0 (2026-09-24). Generated from `spec/antikythera.json`, `out/verify_all.json`, `out/check.json`, `out/build_report.json` and `out/print/*/print_report.json`.

## Status

**All 10 acceptance criteria are GREEN.** No problem was found in the spec data; no fallback of section 8 was needed.

| # | Criterion (section 9) | State |
|---|---|---|
| 1 | Spec fingerprint identical | GREEN |
| 2 | Exact solver: DOF 1, rates, 22 targets | GREEN |
| 3 | Meshes: centre distances, modules, face overlap, eps, z >= 8, nominal tip land; crowns by BVH (a) | GREEN |
| 4 | 2D interference: 0 penetration (j = 0.03) | GREEN |
| 5 | Pre-filter 0 conflicts, a1 keep-out, follower sectors, cosmos checks | GREEN |
| 6 | Drivers valid/simple/untruncated, readback < 1e-5 rad, cycles closed | GREEN |
| 7 | BVH: 0 overlapping pairs on every sample (dials and case included, FONT excluded) | GREEN |
| 8 | Meshes closed, manifold, contiguous, volume = area x thickness (crowns per shell) | GREEN |
| 9 | Deliverables present; am.blend animates without Python scripts | GREEN |
| 10 | PROGRESS.md / DECISIONS.md up to date; deviations listed | GREEN |

## Trains and periods

Periods in days use the model year = 1 tropical year = 365.2422 days. Deviations are relative to `reference_values_days` (modern values); each train reproduces its ancient period relation exactly.

| Output | Chain | Exact rate (rev/y) | Cycle | Period (d) | Reference (d) | Rel. dev. |
|---|---|---|---|---|---|---|
| Crank a (turns/year) | a1 (crown) ~ b1 | 223/48 | definition 223/48 | - | - | - |
| Mean Sun / date pointer b | b1 (input) | 1 | tropical year | 365.2422 | 365.2422 | +0.00e+00 |
| Moon pointer (mean sidereal) | b2>c1, c2>d1, d2>e2, e5>k1 ~pin~ k2>e6, e1>b3 | 254/19 | 254 sidereal months / 19 y | 27.3213 | 27.3217 | -1.44e-05 |
| Moon phase q1 (synodic) | b0 ~ q1 (crown differential on the Moon pointer) | 235/19 | synodic month | 29.5302 | 29.5306 | -1.25e-05 |
| Lunar anomaly k1 on e3 | e5>k1 relative to the e3 turntable | 56165/4237 | anomalistic month | 27.5533 | 27.5545 | -4.53e-05 |
| Lunar apsidal line e3 | b2>l1, l2>m1, m3>e3 | -477/4237 | 8.88 y | 3244.3002 | 3232.6054 | +3.62e-03 |
| Draconic month (Moon - nodes) | moon - t_nodes | 23717/1767 | draconic month | 27.2118 | 27.2122 | -1.44e-05 |
| Dragon Hand (nodes) | fx49>nd62, nd64>nd48 (spB on b) | -5/93 | 18.6 y retrograde | 6793.5049 | 6793.4800 | +3.67e-06 |
| Metonic pointer (5 turns) | b2>l1, l2>m1, m2>n1 | -5/19 | 19 y = 235 synodic months | 6939.6018 | 6939.6884 | -1.25e-05 |
| Olympiad pointer | ... m2>n1, n3>o1 | 1/4 | 4-year games cycle | 1460.9688 | - | - |
| Callippic pointer | ... m2>n1, n2>p1, p2>cal1 | -1/76 | 76 y = 940 synodic months | 27758.4072 | 27758.7536 | -1.25e-05 |
| Saros pointer (4 turns) | ... l2>m1, m3>e3, e4>f1, f2>g1 | -940/4237 | 223 synodic months | 6585.2392 | 6585.3213 | -1.25e-05 |
| Exeligmos pointer | ... f2>g1, g2>h1, h2>i1 | -235/12711 | 3 Saros | 19755.7175 | 19755.9639 | -1.25e-05 |
| Mercury epicycle (synodic) | fx51>me72, me89>me40>me20 (on b), pin + follower | 1513/480 | 1513 synodic periods / 480 y | 115.8733 | 115.8800 | -5.81e-05 |
| Venus epicycle (synodic) | fx51>vn44, vn34>vn26>r1 (on b), pin + follower | 289/462 | 289 synodic periods / 462 y | 583.8820 | 583.9200 | -6.51e-05 |
| True-Sun epicycle su56 (anomaly) | fx56>cp52>su56 (on CP), eccentric pin + follower | -1 | anomalistic year ~ tropical year | 365.2422 | 365.2422 | +0.00e+00 |
| Mars pin gear (synodic) | fx56>cp64, ma38>ma40>ma71 | 133/284 | 133 syn / 284 y | 779.9157 | 779.9400 | -3.12e-05 |
| Mars output (sidereal) | ... ma71 ~pin~ ma80s>ma80o | 151/284 | 151 sid / 284 y | 686.9456 | 686.9800 | -5.01e-05 |
| Jupiter pin gear (synodic) | fx56>cp64, ju45>ju40>ju43 | 315/344 | 315 syn / 344 y | 398.8677 | 398.8800 | -3.09e-05 |
| Jupiter output (sidereal) | ... ju43 ~pin~ ju65s>ju65o | 29/344 | 29 sid / 344 y | 4332.5282 | 4332.5890 | -1.40e-05 |
| Saturn pin gear (synodic) | fx56>cp52, sa61>sa40>sa68 | 427/442 | 427 syn / 442 y | 378.0727 | 378.0900 | -4.57e-05 |
| Saturn output (sidereal) | ... sa68 ~pin~ sa86s>sa86o | 15/442 | 15 sid / 442 y | 10762.4702 | 10759.2200 | +3.02e-04 |

## Kinematics (exact)

- Unknowns 45 (mobile bodies except frame, a, q); equations 44 = 37 Willis + 4 pin-slot + 3 followers.
- Rank **44**, degrees of freedom **1**, inconsistent constraints 0; rank with input w_b = 1: 45.
- Mean rates equal to `rate_abs_mean` for all bodies: True; targets exact: 22/22.

| Target | Expr | Expected | Solver | OK |
|---|---|---|---|---|
| crank | a | 223/48 | 223/48 | GREEN |
| mean Sun | b | 1 | 1 | GREEN |
| Moon (mean sidereal) | moon | 254/19 | 254/19 | GREEN |
| lunar apsidal line | e_table | -477/4237 | -477/4237 | GREEN |
| lunar anomaly phase (k1 relative to e3) | k@e_table | 56165/4237 | 56165/4237 | GREEN |
| Moon phase (q1 relative to Moon pointer, magnitude) | q@moon | 235/19 | 235/19 | GREEN |
| Metonic pointer | n | -5/19 | -5/19 | GREEN |
| Olympiad pointer | o | 1/4 | 1/4 | GREEN |
| Callippic pointer | cal | -1/76 | -1/76 | GREEN |
| Saros pointer | g | -940/4237 | -940/4237 | GREEN |
| Exeligmos pointer | i | -235/12711 | -235/12711 | GREEN |
| Dragon Hand (nodes) | t_nodes | -5/93 | -5/93 | GREEN |
| draconic month (Moon - nodes) | moon-t_nodes | 23717/1767 | 23717/1767 | GREEN |
| Mercury epicycle relative to b1 | x_me20@b | 1513/480 | 1513/480 | GREEN |
| Venus epicycle relative to b1 | x_r1@b | 289/462 | 289/462 | GREEN |
| true-Sun epicycle absolute | x_su56 | 0 | 0 | GREEN |
| Mars pin gear relative to CP | x_ma71@b | 133/284 | 133/284 | GREEN |
| Jupiter pin gear relative to CP | x_ju43@b | 315/344 | 315/344 | GREEN |
| Saturn pin gear relative to CP | x_sa68@b | 427/442 | 427/442 | GREEN |
| Mars output | t_mars | 151/284 | 151/284 | GREEN |
| Jupiter output | t_jupiter | 29/344 | 29/344 | GREEN |
| Saturn output | t_saturn | 15/442 | 15/442 | GREEN |

## Cosmos checks (section 5.8)

| Check | Values | State |
|---|---|---|
| elongation_mercury | max_abs_elongation_deg = 22.9545, limit_deg = 22.9545, marker_local_deg_is_minus_g0 = True | GREEN |
| elongation_venus | max_abs_elongation_deg = 46.0367, limit_deg = 46.0367, marker_local_deg_is_minus_g0 = True | GREEN |
| elongation_trueSun | max_abs_elongation_deg = 2.3880, limit_deg = 2.3880, marker_local_deg_is_minus_g0 = True | GREEN |
| retrograde_saturn | max_dev_from_180_deg = 8.527e-14, marker_local_deg = 0.0000, marker_is_180_plus_beta = True | GREEN |
| retrograde_jupiter | max_dev_from_180_deg = 0.0000, marker_local_deg = 0.0000, marker_is_180_plus_beta = True | GREEN |
| retrograde_mars | max_dev_from_180_deg = 0.0018, marker_local_deg = 150.0000, marker_is_180_plus_beta = True | GREEN |
| solar_apogee | apogee_longitude_deg = 65.5001 | GREEN |
| lunar_anomaly | amplitude_deg = 6.5796, asin_e_over_r_deg = 6.5796 | GREEN |
| pins_in_slots | max_angle_error_rad = 7.222e-11 | GREEN |

## Modules and centre distances (37 external meshes)

| Mesh | Carrier | Module | Centre distance | Error (mm) | Face overlap | eps | eps spec | 2D min signed | Backlash near | OK |
|---|---|---|---|---|---|---|---|---|---|---|
| b2~c1 | frame | 0.480000 | 24.480000 | 4.4e-11 | 1.30 | 1.391 | 1.391 | 0.0130 | 0.0130 | GREEN |
| c2~d1 | frame | 0.447200 | 16.099200 | 2.2e-11 | 1.30 | 1.361 | 1.361 | 0.0130 | 0.0130 | GREEN |
| d2~e2 | frame | 0.485500 | 38.597250 | 5.6e-11 | 1.00 | 1.398 | 1.398 | 0.0130 | 0.0130 | GREEN |
| b2~l1 | frame | 0.480000 | 24.480000 | 4.6e-11 | 1.50 | 1.391 | 1.391 | 0.0130 | 0.0130 | GREEN |
| l2~m1 | frame | 0.496600 | 36.996700 | 2.6e-11 | 1.50 | 1.413 | 1.413 | 0.0130 | 0.0130 | GREEN |
| m3~e3 | frame | 0.466000 | 58.250000 | 1.2e-11 | 1.40 | 1.397 | 1.397 | 0.0130 | 0.0130 | GREEN |
| e5~k1 | e_table | 0.512000 | 25.600000 | 4.8e-11 | 0.50 | 1.394 | 1.394 | 0.0130 | 0.0130 | GREEN |
| k2~e6 | e_table | 0.534000 | 26.700000 | 3.4e-12 | 0.50 | 1.394 | 1.394 | 0.0130 | 0.0130 | GREEN |
| e1~b3 | frame | 0.559400 | 17.900800 | 2.8e-11 | 1.30 | 1.359 | 1.359 | 0.0130 | 0.0130 | GREEN |
| e4~f1 | frame | 0.520300 | 62.696150 | 3.2e-11 | 1.30 | 1.423 | 1.423 | 0.0130 | 0.0130 | GREEN |
| f2~g1 | frame | 0.516700 | 21.701400 | 2.9e-11 | 1.20 | 1.376 | 1.376 | 0.0130 | 0.0130 | GREEN |
| g2~h1 | frame | 0.447500 | 17.900000 | 1.6e-11 | 1.00 | 1.358 | 1.358 | 0.0130 | 0.0130 | GREEN |
| h2~i1 | frame | 0.434700 | 16.301250 | 4.3e-11 | 1.20 | 1.340 | 1.34 | 0.0130 | 0.0130 | GREEN |
| m2~n1 | frame | 0.514000 | 17.476000 | 0.0e+00 | 1.50 | 1.336 | 1.336 | 0.0130 | 0.0130 | GREEN |
| n3~o1 | frame | 0.417100 | 24.400350 | 3.6e-15 | 1.10 | 1.404 | 1.404 | 0.0130 | 0.0130 | GREEN |
| n2~p1 | frame | 0.500000 | 18.750000 | 1.5e-11 | 1.30 | 1.340 | 1.34 | 0.0130 | 0.0130 | GREEN |
| p2~cal1 | frame | 0.500000 | 18.000000 | 5.7e-11 | 1.30 | 1.324 | 1.324 | 0.0130 | 0.0130 | GREEN |
| fx49~nd62 | b | 0.486486 | 27.000000 | 4.4e-11 | 1.00 | 1.400 | 1.4 | 0.0130 | 0.0130 | GREEN |
| nd64~nd48 | b | 0.482143 | 27.000000 | 9.5e-12 | 1.00 | 1.400 | 1.4 | 0.0130 | 0.0130 | GREEN |
| fx51~vn44 | b | 0.538947 | 25.600000 | 1.8e-11 | 1.00 | 1.390 | 1.39 | 0.0130 | 0.0130 | GREEN |
| vn34~vn26 | b | 0.521000 | 15.630000 | 5.9e-11 | 1.00 | 1.352 | 1.352 | 0.0130 | 0.0130 | GREEN |
| vn26~r1 | b | 0.521000 | 23.184500 | 1.5e-11 | 1.00 | 1.374 | 1.374 | 0.0130 | 0.0130 | GREEN |
| fx51~me72 | b | 0.538947 | 33.145263 | 1.7e-11 | 1.00 | 1.405 | 1.405 | 0.0130 | 0.0130 | GREEN |
| me89~me40 | b | 0.500000 | 32.250000 | 1.9e-11 | 1.00 | 1.401 | 1.401 | 0.0130 | 0.0130 | GREEN |
| me40~me20 | b | 0.500000 | 15.000000 | 3.8e-11 | 1.00 | 1.344 | 1.344 | 0.0130 | 0.0130 | GREEN |
| fx56~cp52 | b | 0.480000 | 25.920000 | 2.7e-11 | 1.00 | 1.399 | 1.399 | 0.0130 | 0.0130 | GREEN |
| cp52~su56 | b | 0.480000 | 25.920000 | 3.6e-11 | 1.00 | 1.399 | 1.399 | 0.0130 | 0.0130 | GREEN |
| fx56~cp64 | b | 0.480000 | 28.800000 | 4.5e-11 | 1.00 | 1.405 | 1.405 | 0.0130 | 0.0130 | GREEN |
| sa61~sa40 | b | 0.480000 | 24.240000 | 2.4e-11 | 1.00 | 1.392 | 1.392 | 0.0130 | 0.0130 | GREEN |
| sa40~sa68 | b | 0.480000 | 25.920000 | 2.4e-11 | 1.00 | 1.395 | 1.395 | 0.0130 | 0.0130 | GREEN |
| sa86s~sa86o | b | 0.480000 | 41.280000 | 1.9e-11 | 1.00 | 1.423 | 1.423 | 0.0130 | 0.0130 | GREEN |
| ju45~ju40 | b | 0.480000 | 20.400000 | 2.1e-12 | 1.00 | 1.382 | 1.382 | 0.0130 | 0.0130 | GREEN |
| ju40~ju43 | b | 0.480000 | 19.920000 | 4.1e-11 | 1.00 | 1.381 | 1.381 | 0.0130 | 0.0130 | GREEN |
| ju65s~ju65o | b | 0.480000 | 31.200000 | 2.2e-11 | 1.00 | 1.410 | 1.41 | 0.0130 | 0.0130 | GREEN |
| ma38~ma40 | b | 0.480000 | 18.720000 | 2.5e-11 | 1.00 | 1.376 | 1.376 | 0.0130 | 0.0130 | GREEN |
| ma40~ma71 | b | 0.480000 | 26.640000 | 1.2e-11 | 1.00 | 1.396 | 1.396 | 0.0130 | 0.0130 | GREEN |
| ma80s~ma80o | b | 0.480000 | 38.400000 | 1.9e-11 | 1.00 | 1.420 | 1.42 | 0.0130 | 0.0130 | GREEN |

Tip lands: minimum nominal tip land 0.228 m (p2); minimum thinned (j = 0.03) tip land 0.0964 mm; root fillet between 0.144 m and 0.200 m (reduced where two fillets would not fit).

## Verification results

- Spec SHA-256 `18934c80264941ed315ced4273d0b16d733132a296d64e25300bea5576ab86b3` (identical); 24/24 section fingerprints: True.
- Phasing: 28 spur components, 65 gears phased (b1, b0 at local 0; crowns pre-phased).
- Pre-filter: 228 parts, 4251 z-overlapping pairs of different bodies, **0 conflicts**, 83 intended contacts (meshes, pin-slots, shafts in plate holes, slider pins in grooves), 168 pairs retained for the BVH.
- a1 keep-out: largest radius carried by b between z 4.6 and 33.73 (b1 excepted): 63.1471 mm (limit 63.6).
- Follower sectors (relative to b): {'mercury_follower': [-48.954, -3.046], 'venus_follower': [108.963, 201.037], 'true_sun_follower': [147.612, 152.388]}; no b-carried object in them except the intended pins.
- Driver expressions: 47 bodies, max length 120, max error 6.719e-13 rad vs the solver over 200 samples in [-50, 50].
- Blender drivers: 51 on objects, all valid True, all simple True, expressions identical True; readback max error 5.999e-07 rad over 50 float32 crank values.
- Cycle closure: metonic after 19.0000 y: 0.0000 rad, olympiad after 4.0000 y: 0.0000 rad, callippic after 76.0000 y: 0.0000 rad, saros after 18.0298 y: 3.020e-07 rad.
- Crank F-curve: {'1': 0.0, '61': 0.5, '481': 4.0, '961': 8.0} (frames 1/61/481/961), extrapolation LINEAR.
- BVH (world coordinates, overlap()): (a) 39 meshes x 50 positions per pitch: 0 overlaps; (b) 7 pin-slots/followers + 2 spiral sliders x 72 positions per relative cycle: 0 overlaps; (c) 168 retained pairs x 240 crank values (120 on [0,1] + 120 random on [0,76], seed 20260924): 0 overlaps. Sanity test: known intersections and a half-pitch mis-phased gear are detected.
- Meshes: 228 mesh objects, all closed/manifold/contiguous: True; extruded volumes = area x (float32(z1) - float32(z0)), max relative error 3.312e-13.
- Spirals: slider pin vs rho(psi): {'metonic': '1.206e-04 mm', 'saros': '1.150e-04 mm'}.
- Units: ['METRIC', 'MILLIMETERS', 0.0010000000474974513]; controller `crank` and `patina` float: True / True.

## FONT texts (excluded from manifold, BVH and print checks)

Built-in font, extrusion 0.025 (0.05 thick), body frame, collection AM_DIALS. Missing glyphs (compared with the notdef box of U+10300): none. The stigma is written ΙΣΤ as in the spec.

| Text | Content | z range | Closest moving part overlapping in xy (dz, part) | OK |
|---|---|---|---|---|
| txt_zodiac_00 | ΚΡΙΟΣ | 41.600..41.650 | 1.000 date_pointer | GREEN |
| txt_zodiac_01 | ΤΑΥΡΟΣ | 41.600..41.650 | 1.000 date_pointer | GREEN |
| txt_zodiac_02 | ΔΙΔΥΜΟΙ | 41.600..41.650 | 1.000 date_pointer | GREEN |
| txt_zodiac_03 | ΚΑΡΚΙΝΟΣ | 41.600..41.650 | 1.000 date_pointer | GREEN |
| txt_zodiac_04 | ΛΕΩΝ | 41.600..41.650 | 1.000 date_pointer | GREEN |
| txt_zodiac_05 | ΠΑΡΘΕΝΟΣ | 41.600..41.650 | 1.000 date_pointer | GREEN |
| txt_zodiac_06 | ΧΗΛΑΙ | 41.600..41.650 | 1.000 date_pointer | GREEN |
| txt_zodiac_07 | ΣΚΟΡΠΙΟΣ | 41.600..41.650 | 1.000 date_pointer | GREEN |
| txt_zodiac_08 | ΤΟΞΟΤΗΣ | 41.600..41.650 | 1.000 date_pointer | GREEN |
| txt_zodiac_09 | ΑΙΓΟΚΕΡΩΣ | 41.600..41.650 | 1.000 date_pointer | GREEN |
| txt_zodiac_10 | ΥΔΡΟΧΟΟΣ | 41.600..41.650 | 1.000 date_pointer | GREEN |
| txt_zodiac_11 | ΙΧΘΥΕΣ | 41.600..41.650 | 1.000 date_pointer | GREEN |
| txt_month_00 | ΘΩΥΘ | 42.450..42.500 | 0.150 date_pointer | GREEN |
| txt_month_01 | ΦΑΩΦΙ | 42.450..42.500 | 0.150 date_pointer | GREEN |
| txt_month_02 | ΑΘΥΡ | 42.450..42.500 | 0.150 date_pointer | GREEN |
| txt_month_03 | ΧΟΙΑΚ | 42.450..42.500 | 0.150 date_pointer | GREEN |
| txt_month_04 | ΤΥΒΙ | 42.450..42.500 | 0.150 date_pointer | GREEN |
| txt_month_05 | ΜΕΧΙΡ | 42.450..42.500 | 0.150 date_pointer | GREEN |
| txt_month_06 | ΦΑΜΕΝΩΘ | 42.450..42.500 | 0.150 date_pointer | GREEN |
| txt_month_07 | ΦΑΡΜΟΥΘΙ | 42.450..42.500 | 0.150 date_pointer | GREEN |
| txt_month_08 | ΠΑΧΩΝ | 42.450..42.500 | 0.150 date_pointer | GREEN |
| txt_month_09 | ΠΑΥΝΙ | 42.450..42.500 | 0.150 date_pointer | GREEN |
| txt_month_10 | ΕΠΙΦΙ | 42.450..42.500 | 0.150 date_pointer | GREEN |
| txt_month_11 | ΜΕΣΟΡΗ | 42.450..42.500 | 0.150 date_pointer | GREEN |
| txt_month_12 | ΕΠΑΓΟΜΕΝΑΙ | 42.450..42.500 | 0.150 date_pointer | GREEN |
| txt_olympiad_0 | ΙΣΘΜΙΑ | -16.550..-16.500 | 0.850 metonic_pointer | GREEN |
| txt_olympiad_1 | ΟΛΥΜΠΙΑ | -16.550..-16.500 | 0.850 metonic_pointer | GREEN |
| txt_olympiad_2 | ΝΕΜΕΑ | -16.550..-16.500 | 0.850 metonic_pointer | GREEN |
| txt_olympiad_3 | ΠΥΘΙΑ | -16.550..-16.500 | 0.850 metonic_pointer | GREEN |
| txt_exeligmos_1 | Η | -16.550..-16.500 | 0.850 saros_pointer | GREEN |
| txt_exeligmos_2 | ΙΣΤ | -16.550..-16.500 | 0.850 saros_pointer | GREEN |

## Parts by status

**SURVIVING** (93): main_plate, stud_c, stud_l, a1, a_shaft, b1, b2, b1_hub, b_hub, short_pillar_1, short_tenon_1, short_pillar_2, short_tenon_2, long_pillar_1, long_tenon_1, long_pillar_2, long_tenon_2, long_pillar_3, long_tenon_3, long_pillar_4, long_tenon_4, d_plate, d_post_1, d_post_2, stud_r1, r1, hub_r1, venus_disk, pin_venus, b3, moon_arbor, q1, q_arbor, c2, c1, d1, d2, e2, e5, e3, e4, e1, e6, k1, k2, l2, l1, m1, m2, f1, f2, g1, g2, h1, h2, i1, o1, shaft_d, shaft_e_inner, pipe_e, shaft_f, shaft_g, shaft_h, shaft_i, shaft_o, hub_c, hub_l, boss_k, stud_kp, e4_spacers, pin_lunar, metonic_pointer, metonic_slider, metonic_slider_pin, saros_pointer, saros_slider, saros_slider_pin, olympiad_pointer, exeligmos_pointer, metonic_cells, metonic_rim, saros_cells, saros_rim, olympiad_dial, exeligmos_dial, zodiac_ring, zodiac_marks, calendar_ring, calendar_marks, parapegma_1, parapegma_lines_1, parapegma_2, parapegma_lines_2

**RECONSTRUCTED** (26): back_plate, front_plate, frame_pillar_1, frame_pillar_2, frame_pillar_3, frame_pillar_4, date_pointer, m3, n1, n3, n2, p1, p2, cal1, shaft_m, shaft_n, shaft_p, shaft_cal, callippic_pointer, callippic_dial, case_left, case_bottom, case_top, case_right, case_cover_front, case_cover_back

**HYPOTHETICAL** (109): crank_bracket, fixed_tube, fx51, fx49, fx56, sub_plate, spacer_ring, standoff_1, standoff_2, standoff_3, crank_arm, crank_knob, b0, t_meanSun, t_date, mean_sun_bar, mean_sun_post, strap, cp, stud_spA, stud_spB, stud_spC, stud_me40, stud_me20, stud_vn26, stud_sa40, stud_ju40, stud_ma40, boss_sa68, stud_sa86s, boss_ju43, stud_ju65s, boss_ma71, stud_ma80s, me72, me89, nd62, nd64, vn44, vn34, me40, me20, vn26, cp52, sa61, cp64, ma38, ju45, su56, sa40, sa68, sa86s, ju40, ju43, ju65s, ma40, ma71, ma80s, hub_spA, hub_spB, hub_spC, hub_me40, hub_me20, hub_vn26, shaft_cp52, shaft_cp64, shaft_su56, crank_disc_su56, hub_sa40, hub_ju40, hub_ma40, mercury_disk, pin_saturn, pin_jupiter, pin_mars, pin_mercury, pin_trueSun, moon_pointer, moon_hanger_1, moon_hanger_2, phase_sphere_dark, phase_sphere_silver, nd48, t_nodes, dragon_hand, t_mercury, mercury_follower, ring_mercury, marker_mercury, t_venus, venus_follower, ring_venus, marker_venus, t_trueSun, true_sun_follower, ring_trueSun, marker_trueSun, t_mars, ma80o, ring_mars, marker_mars, t_jupiter, ju65o, ring_jupiter, marker_jupiter, t_saturn, sa86o, ring_saturn, marker_saturn

Collections: {'AM_CASE': 6, 'AM_DIALS': 72, 'AM_HELPERS': 57, 'AM_HYPOTHETICAL': 42, 'AM_RECONSTRUCTED': 11, 'AM_STRUCTURE': 81, 'AM_SURVIVING': 47}

## Print export

| Profile | Files | 2D check | STL re-import rel. err | Larger than the bed | Fragile tips (tip land mm) | Walls |
|---|---|---|---|---|---|---|
| resin_x1 | 228 STL + 3MF (13.7 MB, 228 objects, closed True) | True (backlash near 0.0217..0.0218 mm) | b1 6.5e-07, a1 1.4e-04, main_plate 0.0e+00, marker_trueSun 2.4e-07 | main_plate, back_plate, front_plate, b1, cp, ring_saturn, metonic_cells, metonic_rim, saros_cells, saros_rim, zodiac_ring, zodiac_marks, calendar_ring, calendar_marks, case_left, case_right, case_cover_front, case_cover_back | h2 0.086, p2 0.085 | 0 below 0.40 mm (min 0.502) |
| resin_x1_5 | 228 STL + 3MF (13.8 MB, 228 objects, closed True) | True (backlash near 0.0346..0.0349 mm) | b1 2.0e-06, a1 9.6e-05, main_plate 0.0e+00, marker_trueSun 6.4e-07 | main_plate, back_plate, front_plate, sub_plate, b1, cp, ring_venus, ring_trueSun, ring_mars, ring_jupiter, ring_saturn, e3, e4, metonic_cells, metonic_rim, saros_cells, saros_rim, zodiac_ring, zodiac_marks, calendar_ring, calendar_marks, parapegma_1, parapegma_2, case_left, case_bottom, case_top, case_right, case_cover_front, case_cover_back | h2 0.126, p2 0.124 | 0 below 0.50 mm (min 0.752) |
| fdm_x2 | 228 STL + 3MF (13.9 MB, 228 objects, closed True) | True (backlash near 0.0866..0.0870 mm) | b1 1.7e-06, a1 3.5e-05, main_plate 0.0e+00, marker_trueSun 2.4e-07 | main_plate, back_plate, front_plate, b1, cp, metonic_cells, metonic_rim, saros_cells, saros_rim, zodiac_ring, zodiac_marks, calendar_ring, calendar_marks, parapegma_1, parapegma_lines_1, parapegma_2, parapegma_lines_2, case_left, case_bottom, case_top, case_right, case_cover_front, case_cover_back | b0 0.188, me20 0.188, d1 0.174, m2 0.156, g2 0.156, h2 0.114, n2 0.149, p2 0.111 | 0 below 0.80 mm (min 1.002) |

## Renders

Files: front34.png present, front.png present, back.png present, exploded.png present, antikythera.mp4 present. Stills rendered with Cycles on Metal (Apple M4 GPU - 8 cores), 1920x1080, 256 samples, OpenImageDenoise on GPU, after a warm-up render (kernel compilation). Animation: EEVEE, 480 frames 1280x720 at 24 fps, crank 0 -> 4 years, PNG frames encoded once through the sequencer to H.264/MP4 (movieclip frame_duration = 480).

## Unresolved defaults applied (spec)

- Axis XY coordinates are derived (not published); residuals against CT distances are within ~0.8 mm.
- Angles of H, I, O, P and the K direction on e3 are unpublished design choices.
- Cosmos ring radii are visual estimates from F21 Fig. 7.
- True-Sun eccentricity d = i/24 (Hipparchus); F21SI Table S9 does not give it. Solar apogee set at longitude 65.5 deg (Hipparchus) through followers[trueSun].pin_phase_deg = 84.5.
- Crown teeth (a1, q1) are envelope-generated against the involute spur (clearance 0.04 per flank) instead of the ancient hand-filed form.
- Lunar pin radius 9.6 mm (alternative 9.9).
- Calendar hole count 354 (alternatives 355, 365).
- Epoch phases are uncalibrated (all 0 at crank 0).
- Rear-layout handedness follows Price 1974 (mirror not excluded).
- Main Plate modelled 2.0 thick (Price: double sheet 2 x 2.0-2.3); turntable raised 3.05 mm instead of 2.7 to keep 0.15 mm axial gaps.

## Decisions

- Spec loaded read-only from `spec/antikythera.json`; every constant read as float64 from it — the spec is the single source of truth.
- Solver angles of linear bodies are reduced modulo 2π exactly with `Fraction(rate)*Fraction(t)` — avoids float drift for large t.
- Target `a` = |w_b|·z_b1/z_a1 and `q@moon` = |w_b − w_moon|·z_b0/z_q1, computed from the two crown meshes — both are outside the linear system (§5.1).
- Root fillet = 0.2·m reduced (down to 0.144·m for z ≥ 100) when two fillets would not fit in the narrow 30° root space — keeps a root arc; the fillet stays below rf + 0.2 m, never reached by the mating tip (rf + 0.25 m).
- Lightening windows only when (rim − hub) ≥ 2 mm; count 4/5/6 for rim radius < 10 / < 15 / ≥ 15 mm; arms along local +x — simplest reading of `tooth.lightening` (fx56 has no window).
- e3: 5 windows between 4 and 40 mm, K arm 9.0 mm wide at −38°, other arms 0.12·r — spec asks ≥ 8 for the K arm.
- b1: rim (inner 53) + hub (9) + 4 spokes 15.5 wide; spoke features (flat, bearing OD, pierced block) not modelled because the studs/post are fused to b — cosmetic.
- b1 hub/rivets modelled as an annulus r 3.2..9.0, z 6.65..7.85 — spec "hub and rivets to 7.85".
- c and l get a hub r 1.25..2.5 joining their two wheels — the two wheels of one body must be connected.
- Pillars: small dimension radial; tenons 2.4×3.0 (short) and 4.0×5.0 (long) through matching Strap/CP holes — spec gives only "tenon_to".
- D-plate posts at 22 mm along the 161° line, ±8 mm across — clear of every other part between z 18.8 and 22.85.
- Mean-Sun bar: collar r 3.4, bar 3 wide, end block r 2.2 at Dblock, post r 1.5 — dimensions not given.
- Mercury/Venus/true-Sun levers: bar 3 mm wide, round end, hubs r 4.5 / 5.2 / 6.0 — slot geometry exactly per spec.
- Mercury pin z 12.65..14.9 (`shafts.pins`) instead of 12.6 (`structure.mercury_disk.pin`) — ends inside the slot instead of flush with the lever face (no coplanar contact).
- Moon pointer: hub r 3, bar 3 wide to 62 with pointed tip, window boss r 5.1 with window r 4.1; hangers 2.4 wide (v) — only length/width/window given.
- Back pointers: hub r 2.5 (spirals) / 2.0 (subsidiary), width 2.0 / 1.5, pointed; spiral sliders: block 3.2×3.0 at z −18.35..−17.4 and pin r 0.5 up to z −15.6 (ends inside the groove).
- Back dial marks (cells, rims r 71.2..71.7, subsidiary rings and sector lines) raised 0.3 mm (z −16.8..−16.5) outside the sweep of the pointers; subsidiary sector lines start 0.3 mm beyond the pointer tip.
- Front dials: zodiac ring 0.1 mm raised at z 41.5, 360 ticks; calendar ring per spec with 365 ticks; front-plate hole circle 354 × Ø0.8; parapegma lines are 0.4 mm raised strips (placeholder text).
- Cosmos rings: annulus from the tube inner radius to the ring outer radius (disc + annulus in one piece).
- Case: 4 walls 5 mm (right wall with the Ø3.1 crank hole) + front/back covers hidden (viewport and render).
- Collections: 69 gears and status-bearing mechanism parts in `AM_<status>`; plates, shafts, tubes, studs, hubs, pins and crank parts in `AM_STRUCTURE`; dials/pointers/markers/texts in `AM_DIALS`; case in `AM_CASE`; body empties, controller, cameras, lights in `AM_HELPERS`. Every object carries `status`.
- Frame-child body empties are top-level objects (only children of b, e_table and moon are parented) — world = local for them.
- Body drivers: default F-curve keys cleared (pass-through driver); non-linear bodies read other empties with SINGLE_PROP on `rotation_euler[i]`; linear sub-terms are inlined with exact integer fractions.
- Volume check: contour area computed on the float32-rounded 2D contour (vertices are float32), exactly like the z range of §5.5.
- Pre-filter follower rule applied to every object carried by b (b itself and its children), except coaxial tubes of b (plain radial test).
- Text z-clearance rule interpreted per xy footprint: a moving part whose swept region overlaps the text footprint must be ≥ 0.1 mm away in z (the subsidiary pointers are only 0.1 mm from the plate, so a global reading is impossible).

## Fallbacks (section 8) and deviations

- None: no crown tightening, no flank densification, no remodelling of a non-toothed part, no intermediate empties; Cycles Metal used for the stills.

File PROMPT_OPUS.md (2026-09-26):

# PROMPT MAÎTRE : mécanisme d'Anticythère fonctionnel dans Blender 5.2 (exécution en une seule fois)

> Donne ce prompt tel quel à une session Claude Code neuve (Opus 5.5), lancée dans un **dossier vide**.
> Il contient tout : mission, règles, décisions, formules, pièges connus et la spécification complète déjà
> vérifiée (§12). Aucune autre source n'est nécessaire, et internet n'est pas utilisé.

---

## 0. Mission

Dans le dossier courant, construis un projet qui :

1. charge la spécification JSON du §12, source de vérité unique ;
2. **démontre mathématiquement** en fractions exactes que chaque train d'engrenages reproduit son cycle
   astronomique et que le mécanisme a exactement **un degré de liberté** (la manivelle) ;
3. génère la géométrie 3D de toutes les pièces : 69 engrenages à développante conjugués, arbres, tubes,
   plaques, piliers, tenons-rainures, leviers suiveurs, cadrans avant et arrière, boîtier ;
4. assemble le tout dans **Blender 5.2** avec une manivelle unique qui anime chaque pièce par des drivers ;
5. **vérifie physiquement** qu'aucune pièce ne pénètre une autre sur toute la plage de mouvement ;
6. exporte les pièces pour l'impression 3D, rend des images et une animation, et produit un rapport de vérification.

Le travail est terminé lorsque **tous les livrables du §10 existent** et que chaque critère du §9 est **vert**, ou
marqué ROUGE avec son diagnostic selon la règle « Fin de session et priorités » du §1.

## 1. Règles de travail (non négociables)

- Travaille uniquement dans le dossier courant. Pas d'internet. N'installe rien (pas de pip, brew ni
  extension Blender). Ne modifie pas `/Applications/Blender.app`.
- **Ne pose aucune question** et n'attends aucune validation : tout est décidé ici. Si un détail n'est pas
  spécifié, choisis l'option la plus simple compatible avec la spec et note-la dans `DECISIONS.md`
  (une ligne : décision, raison).
- **La spec est intangible** : ne change aucune valeur. Si un contrôle échoue à cause d'une donnée de la
  spec, n'affaiblis pas le contrôle : applique le repli prévu au §8, sinon signale le problème en tête du rapport.
- N'affaiblis jamais un test ni une tolérance pour le faire passer. Seules les tolérances du §9 s'appliquent.
- Avance étape par étape (§7). À chaque point de contrôle, lance les commandes indiquées et corrige jusqu'au
  vert avant de continuer. Tiens `PROGRESS.md` à jour (étape, état, durée, problèmes et correctifs).
- Toute commande Blender tourne en arrière-plan avec un code de sortie :
  `"$BL" -b --factory-startup --python-exit-code 1 -P script.py -- args`. Journaux dans `out/logs/`.
- Une commande shell ne doit pas dépasser environ 9 minutes : découpe les rendus et les longues
  vérifications (plages de frames, lots d'échantillons), ou lance-les en arrière-plan et surveille leur fin.
- Le paquet `am/` n'importe **jamais** `bpy` ni `mathutils` : il doit être testable hors de Blender. Seuls
  les scripts de `blender_scripts/` touchent à Blender. Pas de dépendance hors bibliothèque standard et numpy.
- **Fin de session et priorités.** Si, après les replis du §8, un critère reste rouge à cause de la spec,
  marque-le ROUGE avec son diagnostic en tête du rapport et passe à l'étape suivante. La session se termine
  quand tous les livrables existent. Ordre de priorité si le temps manque : (1) étapes 0 à 3, (2) étapes 4
  et 5 avec `out/am.blend` animé, (3) rapport, (4) étape 6, (5) impression, (6) rendus Cycles, (7) animation.

## 2. Environnement (vérifié sur cette machine)

```sh
PY=/Applications/Blender.app/Contents/Resources/5.2/python/bin/python3.13   # 3.13.13, numpy 2.3.4, tomllib, fastjsonschema, unittest
BL=/Applications/Blender.app/Contents/MacOS/Blender                         # Blender 5.2.2 LTS
```

- N'utilise **jamais** `/usr/bin/python3` (3.9, sans numpy). Pas de scipy, pytest ni shapely.
- Mac Apple M4, 16 Go ; GPU Metal listé « Apple M4 (GPU - 8 cores) ».

## 3. Le mécanisme en bref (ce que modélise la spec)

- Une **manivelle** latérale tourne l'arbre `a` (axe horizontal +x). Sa couronne **a1** (48 dents) entraîne la
  grande roue **b1** (223 dents) : **1 tour de b1 = 1 année**. Toutes les vitesses sont en tours par an.
- **Trains arrière**, derrière la plaque principale :
  - **Lune** : b2→c→d→e2/e5→k1, puis un **tenon-rainure** k1⇢k2 porté par le plateau tournant **e3**, puis
    k2→e6/e1→b3. Le résultat est la Lune moyenne 254/19 plus l'anomalie d'Hipparque.
  - **Métonique / Olympiade / Callippique** : b2→l→m→n→(o, p→cal).
  - **Saros / Exeligmos** : m3→e3/e4→f→g→h→i.
  - Les deux chemins partis de b2 se rejoignent sur e3 : c'est un vrai différentiel.
- **Trains avant** (modèle Freeth 2021, en grande partie **hypothétiques**) :
  - sur b1 : nœuds (main du dragon), Mercure et Vénus. Ce sont des épicycles portés par b1 qui engrènent
    des roues fixes. Un tenon sur chaque épicycle entraîne un **levier suiveur** monté sur l'axe central ;
  - sur la plaque **CP**, qui tourne avec b1 : Soleil vrai (excentrique + levier) et planètes supérieures
    (Mars, Jupiter, Saturne), chacune avec un tenon-rainure et une roue de sortie sur l'axe central.
- **Sorties** :
  - à l'avant, des tubes concentriques portent des anneaux planétaires, l'aiguille lunaire avec sa sphère
    de phase (différentiel b0/q1), l'aiguille de date et la main du dragon ;
  - à l'arrière, deux spirales (Métonique 5 tours / 235 cases, Saros 4 tours / 223 cases) suivies par des
    aiguilles à coulisseau, plus trois cadrans secondaires.
- Chaque pièce a un **statut** : `SURVIVING`, `RECONSTRUCTED` ou `HYPOTHETICAL`. Il est conservé partout :
  propriétés, collections, couleurs de débogage, rapport.

## 4. Décisions déjà tranchées (ne pas les rediscuter)

1. **Unités** : 1 unité Blender = 1 mm (`unit_settings.system='METRIC'`, `length_unit='MILLIMETERS'`,
   `scale_length=0.001`). `scale_length` est stocké en float32 : compare avec `math.isclose(x, 0.001, rel_tol=1e-6)`,
   jamais `==`. Caméras : `clip_start = 1.0`, `clip_end = 10000.0`. Repère et signes : voir `conventions` dans la
   spec. Taux positif = sens horaire vu de face.
2. **Profil de dent** : développante à **30°**, saillie 1·m, creux 1,25·m, congé de pied 0,2·m, sans
   déport. Jeu **uniquement par amincissement des dents** (0,03 mm pour le modèle savant), **jamais** en
   déplaçant les axes. Modules, positions d'axes et plages Z : ceux de la spec, sans modification.
3. **Couronnes** a1/b1 et b0/q1 : dents **déjà calculées par enveloppe** et vérifiées (spec `crowns`), à
   construire telles quelles (§5.6).
4. **Mouvement** : un Empty `AM_Controller` porte `ctl['crank'] = 0.0` (années) et `ctl['patina'] = 0.0`,
   écrits en **littéraux flottants** : avec `= 0`, la propriété serait entière et l'animation sauterait par
   années entières. Vérifie `type(ctl['crank']) is float` avant `keyframe_insert`, et applique
   `ctl.id_properties_ui('patina').update(min=0.0, max=1.0)`. Chaque corps est un Empty `B_<id>` dont la
   rotation est pilotée par un driver en **expression simple** : pas de fonction Python, pour que le fichier
   s'anime sans autorisation de scripts. **Pas de physique rigide** (Bullet) : elle ne peut pas reproduire
   des rapports exacts.
5. **Hiérarchie** : chaque pièce est un objet enfant de l'Empty de son corps, modélisé en coordonnées
   locales du corps. Les corps dont le parent est `b` ou `e_table` sont enfants de `B_b` ou de
   `B_e_table`. `matrix_parent_inverse` est l'identité partout. La position de l'Empty vaut
   `axis_xy_in_parent` dans le repère du parent. Tous les Empties sont à z = 0, sauf `B_a` (z = axe de a1)
   et `B_q` (z = 52,70 dans `B_moon`).
6. **Collections** : `AM_SURVIVING`, `AM_RECONSTRUCTED`, `AM_HYPOTHETICAL` pour les engrenages et pièces
   à statut ; `AM_STRUCTURE`, `AM_DIALS`, `AM_CASE`, `AM_HELPERS` (Empties). Propriétés personnalisées sur
   chaque objet : `status`, `role`, `teeth`, `module`, `body`, `sources`.
7. **Matériaux** : bronze PBR avec un mélange de patine piloté par `AM_Controller["patina"]` (0 = neuf,
   1 = musée), bois pour le boîtier. `obj.color` = couleur de statut, pour un affichage de débogage en
   Solid/Object.
8. **Incertitudes** : on applique les valeurs par défaut de la spec (`unresolved_defaults`). Le rapport les liste.

## 5. Formules (exactes, à implémenter telles quelles)

### 5.1 Angles et taux
- Angle d'un corps (convention mathématique, sens trigonométrique autour de son axe, relatif à son parent) :
  **θ(t) = −2π · rate_rel_parent · t** pour un corps linéaire, t en années.
- **Willis**, pour un engrènement extérieur de g1 (corps B1) et g2 (corps B2) sur le porteur C :
  z1·(w1 − wC) = −z2·(w2 − wC).
- Le solveur `am/kinematics.py` reconstruit **tous** les taux moyens par élimination de Gauss exacte
  (`fractions.Fraction`) :
  - inconnues : les **45 corps mobiles** hors `frame`, `a` et `q` ;
  - **44 équations** : 37 engrènements extérieurs (Willis), 4 tenons-rainures (taux moyen de la roue à rainure
    = taux moyen de la roue à tenon), 3 suiveurs (taux moyen du suiveur = taux de `b`, car d < i) ;
  - entrée : taux de `b` = 1.
  Il doit trouver : rang 44 (**DDL = 1**), aucune contrainte incohérente, des taux égaux à
  `bodies[].rate_abs_mean`, et **toutes** les `targets`. Deux cibles sont hors solveur et comparées en valeur
  absolue : `a` = 223/48 (définition) et `q@moon` = |w_b − w_moon| = 235/19.

### 5.2 Angles de chaque corps (à utiliser pour les drivers et le solveur)
| corps | parent | axe (repère du parent, mm) | roues | taux moyen absolu | angle θ(t) |
|---|---|---|---|---|---|
| `frame` | — | — | fx51, fx49, fx56 | 0 | fixe |
| `a` | frame | (0.0000, 0.0000) | a1 | — | autour de +x : −2π·(223/48)·t |
| `b` | frame | (0.0000, 0.0000) | b1, b2, b0 | 1 | −2π·(1)·t |
| `moon` | frame | (0.0000, 0.0000) | b3 | 254/19 | monde : θ = −θ_e_inner |
| `c` | frame | (-7.8891, -23.1740) | c2, c1 | -32/19 | −2π·(-32/19)·t |
| `d` | frame | (-13.0733, -38.4156) | d1, d2 | 64/19 | −2π·(64/19)·t |
| `e_pipe` | frame | (14.1105, -11.0151) | e2, e5 | -254/19 | −2π·(-254/19)·t |
| `e_table` | frame | (14.1105, -11.0151) | e3, e4 | -477/4237 | −2π·(-477/4237)·t |
| `e_inner` | frame | (14.1105, -11.0151) | e1, e6 | -254/19 | monde : θ = θ_e_table − θ_kp (θ_kp local à e_table) |
| `k` | e_table | (20.1731, -15.7609) | k1 | 55688/4237 | −2π·(56165/4237)·t (local) |
| `kp` | e_table | (21.0399, -16.4382) | k2 | 55688/4237 | tenon-rainure : θ = θ_k + atan2(1.1·sin(θ_k − β), 9.6 − 1.1·cos(θ_k − β)), β = −38° |
| `l` | frame | (19.8733, 14.2941) | l2, l1 | -32/19 | −2π·(-32/19)·t |
| `m` | frame | (0.0000, 45.5000) | m1, m3, m2 | 53/57 | −2π·(53/57)·t |
| `f` | frame | (19.7179, -73.4600) | f1, f2 | 1692/4237 | −2π·(1692/4237)·t |
| `g` | frame | (0.0000, -82.5240) | g1, g2 | -940/4237 | −2π·(-940/4237)·t |
| `h` | frame | (11.5059, -96.2362) | h1, h2 | 940/12711 | −2π·(940/12711)·t |
| `i` | frame | (-0.2562, -107.5227) | i1 | -235/12711 | −2π·(-235/12711)·t |
| `n` | frame | (0.0000, 62.9760) | n1, n3, n2 | -5/19 | −2π·(-5/19)·t |
| `o` | frame | (-24.4003, 62.9760) | o1 | 1/4 | −2π·(1/4)·t |
| `p` | frame | (12.7650, 76.7098) | p1, p2 | 5/76 | −2π·(5/76)·t |
| `cal` | frame | (24.4003, 62.9760) | cal1 | -1/76 | −2π·(-1/76)·t |
| `q` | moon | (0.0000, 0.0000) | q1 | — | autour de son X local (radial), relatif à `moon` : θ_q = θ_b − θ_moon (NON LINÉAIRE ; moyenne +235/19) |
| `spA` | b | (16.5726, 28.7046) | me72, me89 | 41/24 | −2π·(17/24)·t (local) |
| `spB` | b | (23.3827, -13.5000) | nd62, nd64 | 111/62 | −2π·(49/62)·t (local) |
| `spC` | b | (-12.8000, -22.1703) | vn44, vn34 | 95/44 | −2π·(51/44)·t (local) |
| `x_me40` | b | (28.2742, -1.3476) | me40 | -553/960 | −2π·(-1513/960)·t (local) |
| `x_me20` | b | (32.3566, -15.7814) | me20 | 1993/480 | −2π·(1513/480)·t (local) |
| `x_vn26` | b | (-11.0705, -6.6362) | vn26 | -295/572 | −2π·(-867/572)·t (local) |
| `x_r1` | b | (-25.1954, 11.7488) | r1 | 751/462 | −2π·(289/462)·t (local) |
| `t_nodes` | frame | (0.0000, 0.0000) | nd48 | -5/93 | −2π·(-5/93)·t |
| `x_cp52` | b | (-8.8652, 24.3568) | cp52, sa61 | 27/13 | −2π·(14/13)·t (local) |
| `x_cp64` | b | (2.5101, -28.6904) | cp64, ma38, ju45 | 15/8 | −2π·(7/8)·t (local) |
| `x_su56` | b | (-34.3914, 19.8559) | su56 | 0 | −2π·(-1)·t (local) |
| `x_sa40` | b | (-1.0611, 47.3062) | sa40 | -167/260 | −2π·(-427/260)·t (local) |
| `x_sa68` | b | (22.1400, 35.7495) | sa68 | 869/442 | −2π·(427/442)·t (local) |
| `x_sa86s` | b | (20.6400, 35.7495) | sa86s | 869/442 | tenon-rainure : θ = θ_x_sa68 + atan2(1.5·sin(θ_x_sa68 − β), 14.37 − 1.5·cos(θ_x_sa68 − β)), β = 180° (local à b) |
| `x_ju40` | b | (22.0874, -34.4253) | ju40 | 1/64 | −2π·(-63/64)·t (local) |
| `x_ju43` | b | (28.6000, -15.6000) | ju43 | 659/344 | −2π·(315/344)·t (local) |
| `x_ju65s` | b | (27.0200, -15.6000) | ju65s | 659/344 | tenon-rainure : θ = θ_x_ju43 + atan2(1.58·sin(θ_x_ju43 − β), 8.22 − 1.58·cos(θ_x_ju43 − β)), β = 180° (local à b) |
| `x_ma40` | b | (-3.8512, -46.2964) | ma40 | 27/160 | −2π·(-133/160)·t (local) |
| `x_ma71` | b | (-24.8984, -29.9654) | ma71 | 417/284 | −2π·(133/284)·t (local) |
| `x_ma80s` | b | (-19.2000, -33.2554) | ma80s | 417/284 | tenon-rainure : θ = θ_x_ma71 + atan2(6.58·sin(θ_x_ma71 − β), 10.0 − 6.58·cos(θ_x_ma71 − β)), β = 330° (local à b) |
| `t_saturn` | frame | (0.0000, 0.0000) | sa86o | 15/442 | monde : θ = θ_b − θ_x_sa86s (θ_x_sa86s local à b) |
| `t_jupiter` | frame | (0.0000, 0.0000) | ju65o | 29/344 | monde : θ = θ_b − θ_x_ju65s (θ_x_ju65s local à b) |
| `t_mars` | frame | (0.0000, 0.0000) | ma80o | 151/284 | monde : θ = θ_b − θ_x_ma80s (θ_x_ma80s local à b) |
| `t_mercury` | frame | (0.0000, 0.0000) | — | 1 | suiveur : θ = θ_b + γ0 + atan2(d·sin λ, i + d·cos λ), λ = θ_x_me20 − γ0 ; i = 36.0000, d = 14.0400, γ0 = -26.0000° |
| `t_venus` | frame | (0.0000, 0.0000) | — | 1 | suiveur : θ = θ_b + γ0 + atan2(d·sin λ, i + d·cos λ), λ = θ_x_r1 − γ0 ; i = 27.8000, d = 20.0100, γ0 = 155.0000° |
| `t_trueSun` | frame | (0.0000, 0.0000) | — | 1 | suiveur : θ = θ_b + γ0 + atan2(d·sin λ, i + d·cos λ), λ = θ_x_su56 + 84.5° − γ0 ; i = 39.7117, d = 1.6547, γ0 = 150.0000° |

Détails :
- **Tenon-rainure** : θ_rainure = θ_tenon + atan2(e·sin(θ_tenon − β), r − e·cos(θ_tenon − β)). Les angles
  sont relatifs au porteur ; e = excentricité, r = rayon du tenon, β = `offset_dir_local_deg` en radians. La
  fonction est continue car e < r, et son taux moyen égale celui du tenon.
- **Suiveur** : θ_F = θ_b + γ0 + atan2(d·sin λ, i + d·cos λ), avec γ0 = atan2 de `epicycle_axis_xy_in_b`
  (λ : voir ci-dessous). Le levier (local +x) pointe alors toujours vers le tenon.
- **Phase lunaire** : `B_q` tourne autour de son X local (radial, le long de l'aiguille lunaire), par rapport
  à `B_moon`, de **θ_q = θ_b − θ_moon**, avec les angles monde en z. Loi **non linéaire**, car la Lune porte
  l'anomalie ; taux moyen +235/19 ; θ_q(0) = −0,0773916 rad. Driver : `-2*pi*fmod(c,1) - m`, où `m` est une
  variable `SINGLE_PROP` sur `B_moon.rotation_euler[2]`. N'utilise **jamais** la forme linéaire : les dents de
  q1 dériveraient jusqu'à 11° contre celles de b0.
- **Manivelle** : `B_a` tourne autour de X : **−2π·(223/48)·t**.
- Les valeurs du tableau sont arrondies pour la lecture. **Toutes les constantes** (axes, i, d, γ0, e, r, β,
  phases des tenons) se lisent dans le JSON en float64.
- **Suiveur (précision)** : λ = θ_épicycle_local + φ_t − γ0, avec φ_t = `followers[].pin_phase_deg` en
  radians (0 pour Mercure et Vénus, 84,5° pour le Soleil vrai). Le tenon est à l'angle local φ_t de son épicycle.
- Dans les drivers, garde les angles petits : `fmod(c*N/D, 1)` avant de multiplier par 2π, avec des fractions
  entières exactes. Pour composer un corps non linéaire, lis la rotation locale d'un autre Empty par une
  variable `SINGLE_PROP` sur `rotation_euler[2]` (ou `[0]` pour les axes X). Ne réinjecte **jamais** un angle
  modulé dans un rapport : les rapports utilisent toujours `c`.

### 5.3 Phasage des dents au montage
Pour chaque engrènement extérieur, calculé à t = 0 avec les angles réels des corps (non nuls pour les corps
non linéaires) : soit β12 l'angle de la ligne des centres de l'axe 1 vers l'axe 2 dans le repère du porteur,
φ1 l'angle monde de la dent 0 de g1 (angle du corps + décalage de phase de g1). Alors la dent 0 de g2 doit être
à φ2 = β12 + π + π/z2 − (z1/z2)·(φ1 − β12). Intègre ce décalage de phase dans le maillage de g2. Le graphe
des engrènements extérieurs a 28 composantes (b1 n'engrène que la couronne a1). Dans chacune, donne la phase 0
à une roue racine (la première roue de la composante rencontrée dans `meshes`), puis propage le long de
l'arbre. Deux roues d'un même corps ont des décalages indépendants. Vérifie ensuite chaque paire par le contrôle 2D du §5.8. Les couronnes a1 et q1 sont **déjà
phasées** dans leurs grilles d'enveloppe : la dent 0 est centrée en φ = π/48 (a1) ou π/20 (q1), face à la dent
0 de b1 ou b0, quand l'angle relatif est nul (a1 : θ_a = 0 ; q1 : θ_q = θ_b − θ_moon = 0). Construis les dents aux
φ de la grille **sans aucun décalage**. À t = 0, θ_q(0) = −0,0774 rad est porté par la rotation de `B_q`, et la
dent 0 de b0 est au même angle dans le repère Lune. b1 et b0 gardent leur dent 0 à l'angle local 0.

### 5.4 Profil à développante (numpy, float64)
r = m·z/2 ; rb = r·cos α ; ra = r + m ; rf = r − 1,25·m ; inv(x) = tan x − x.
Demi-angle de dent au rayon ρ ≥ rb : ψ(ρ) = π/(2z) + inv(α) − inv(arccos(rb/ρ)) − j/(4r), où j est le jeu
circonférentiel. Flancs de la dent k (centre θk = 2πk/z + phase) : ρ·(cos(θk ± ψ(ρ)), sin(θk ± ψ(ρ))), avec
ρ de max(rb, rf) à ra, **au moins 24 points par flanc**. Si rf < rb (z < 19 à 30°), prolonge radialement
de rb à rf. Arc de tête à ra, arc de pied à rf, congé ≈ 0,2·m. Retire les points consécutifs confondus
(tolérance 1e-9) : `me.validate()` ne les fusionne pas.
- **Largeur en tête** (`tooth.tip_land_rule`) : ≥ 0,2·m sur le profil **nominal** (j = 0) ; sur les profils
  amincis, > 0, valeur seulement rapportée.
- **Évidements** : suis exactement `tooth.lightening`. Pas de fenêtres pour les roues à tenon ou à rainure ;
  e3 a un bras vers K ; pour **b1**, les 4 rayons A/B/C/D de `b1_structure` ; **e4** est un anneau.
- **Alésage** de chaque roue : `gears[].bore_radius`. Une roue `fused` fait partie du corps de son arbre ; une
  roue `rides_on` tourne sur un support d'un autre corps avec 0,05 mm de jeu. Arbres, goujons, bossages, moyeux
  et tenons : exactement la table `shafts` (rayons et plages Z).
- **Cercles avec jeu** (alésages, trous, goujons, bossages, tubes) : polygones de
  n ≥ max(64, ⌈π/acos(R/(R+g))⌉ + 8) côtés, avec le même n pour l'alésage et l'arbre.

### 5.5 Maillages dans Blender
Extrude les contours 2D (extérieur + trous) entre z0 et z1. Triangule chaque face plane avec
`mathutils.geometry.delaunay_2d_cdt(pts2d, [], [boucle_ext, trou1, …], 3, 1e-9)` (output_type 3 : triangles
intérieurs, trous retirés). **N'utilise pas `tessellate_polygon`**, faux sur ces contours (§11). Contrôle : aucun
sommet ajouté (sinon le contour se recoupe : corrige-le), n + 2·(nombre de trous) − 2 triangles, aucune arête
partagée par plus de 2 triangles. Remplis ensuite `vertices`, `loops` et `polygons` avec `foreach_set` (pas de
`from_pydata` ni de bmesh dent par dent). Ensuite `me.validate()`,
`me.shade_smooth()`, `me.set_sharp_from_angle(angle=radians(30))`. **Orientation** : le contour extérieur en
sens trigonométrique, chaque trou en sens horaire (aire signée), parois générées dans ce sens. Chaque maillage
doit être **fermé, variété, orienté de façon cohérente** : aucune arête bmesh avec
`is_manifold and not is_contiguous`. Son volume, calculé en float64 sur les sommets relus, doit valoir
aire du contour × (float32(z1) − float32(z0)) à 1e-6 près (relatif), avec float32(z) = `float(numpy.float32(z))`
(les sommets sont stockés en float32). Pas de modificateur booléen sur la géométrie vérifiée.

### 5.6 Couronnes (contrates) : dents précalculées par enveloppe
Les dents de a1 et q1 sont **fournies** dans `crowns.a1.envelope` et `crowns.q1.envelope`. Ce sont des grilles
(s, ρ, φ_lo, φ_hi) calculées comme la région que les dents de b1 ou b0 (jeu 0,03 et marge 0,04 par flanc) ne
balaient jamais. Elles ont été vérifiées dans Blender 5.2.2 : **0 recouvrement BVH** sur 60 positions par pas, et
un jeu minimal de 0,013 à 0,041 mm à chaque position, donc un engrènement continu. **Ne les recalcule pas.**
Construis chaque dent selon `crowns.mesh_rule`, répète-la z fois (φ += k·2π/z), et ajoute le disque, l'arbre, la
manivelle (a1), l'arbre radial, les supports et la sphère de phase (q1) aux cotes du bloc `crowns`. Les dents
pénètrent le disque de 0,05 mm : ce sont des coques fermées séparées dans le même objet (même corps), et le
contrôle de variété se fait par coque. Repères : a1, s = x monde et φ autour de +x depuis −z vers +y ; q1, s = u
du repère Lune et φ autour de +u depuis −z vers +v.

### 5.7 Spirales arrière et coulisseaux
Repère arrière (u, v) = (−x, y). ψ = angle du corps n (Métonique) ou g (Saros), positif = sens horaire vu de
l'arrière = +θ en convention monde. On a k = floor(ψ/2π), φ = ψ − 2πk, R_k = r_start + k·pitch,
δ = pitch/2. Si φ < π, ρ = R_k. Sinon ρ = δ·cos φ + sqrt((R_k + δ)² − δ²·sin²φ). Le deuxième centre est au
centre du cadran + (0, +δ) en (u, v). La rainure (largeur 1,2) est taillée dans la plaque arrière le long de
cette spirale, pour ψ de 0 à tours·2π, avec des **extrémités rondes** (r 0,6) centrées sur les points
ψ = 0 et ψ = tours·2π. Les cases sont des traits radiaux entre les tours : 47 par tour pour le Métonique, 223
sur 4 tours pour le Saros. Le coulisseau (tenon r 0,5, appartenant au corps n ou g de son aiguille) glisse le
long du +y local de l'aiguille. Sa position `location.y` est pilotée par un driver qui calcule ψ_mod
**directement depuis c**, jamais depuis la rotation modulée de l'aiguille :
- Métonique : `10*pi*fmod(fmod(c/19,1)+1,1)` ;
- Saros : `8*pi*fmod(fmod(c*235/4237,1)+1,1)`.
La F-curve de ce driver est une **table de correspondance** ψ→ρ : ≥ 1800 clés, interpolation LINEAR. Vide
d'abord les 2 clés par défaut avec `fc.keyframe_points.clear()`.

### 5.8 Contrôles géométriques 2D (dans `am/`)
- Rapport de conduite ε = (√(ra1² − rb1²) + √(ra2² − rb2²) − a·sin α) / (π·m·cos α) ≥ 1,2.
- Interférence 2D d'une paire : 50 positions relatives sur un pas de dent. Distance signée minimale entre
  contours ≥ 0 (aucune pénétration), et jeu mesuré dans [0,4·j ; 3·j] près de la ligne des centres.
- **Pré-filtre de collisions.** Objets : roues (anneau alésage→tête), tubes, arbres, goujons, bossages et
  moyeux (`shafts.items`), tenons (anneau balayé autour de l'axe de leur corps), piliers, disques, leviers,
  anneaux, marqueurs, aiguilles et plaques. Pour chaque paire d'objets de **corps différents** dont les plages Z
  se recouvrent, compare les régions balayées :
  - porteur `b` (tout ce qui en dépend) : anneau autour de (0,0) ;
  - porteur `e_table` : anneau autour de E ;
  - repère fixe : cercle statique ;
  - deux objets rigides du même porteur : positions réelles ;
  - objets coaxiaux : intervalles radiaux, avec un jeu ≥ 0,04 (palier) ; sinon jeu ≥ 0,15 ;
  - leviers suiveurs : seuls comptent les objets de `b` dans leur secteur (`layers.swing_sectors`).
  **Contacts voulus**, exclus du comptage du pré-filtre mais testés au BVH : paires de `meshes` ; tenon ↔ sa
  rainure (`shafts.pins[].slot_in`) ; arbres, tubes et tenons ↔ plaques traversées (trous de jeu r + 0,05). Les
  objets d'un **même corps** ne sont ni comptés ni testés. **Paires retenues** (pour le BVH §5.9 c) : objets de
  corps différents dont les plages Z se recouvrent ou sont à moins de 0,1 mm, et dont les régions balayées sont
  à moins de 0,5 mm, contacts voulus compris.
- **Cosmos** (contrôle de sens) : élongation de Mercure, Vénus et du Soleil vrai par rapport au Soleil moyen
  dans ±asin(d/i) ; rétrogradation de Mars, Jupiter et Saturne à l'opposition (180 ± 1°) ; apogée solaire à la
  longitude 65,5 ± 0,5° ; amplitude de l'anomalie lunaire de 6,58° ; chaque tenon toujours dans sa rainure.
  Longitude affichée = −(θ_corps + marker_local_deg), le zodiaque croissant dans le sens horaire vu de face.

### 5.9 Contrôles 3D dans Blender (`check.py`)
- Pour chaque échantillon v, stocke une valeur **exactement représentable en float32** :
  `c = float(numpy.float32(v)); ctl['crank'] = c`, puis `ctl.update_tag()` et `view_layer.update()`. La
  propriété est un double mais le driver la lit en float32 ; compare au solveur évalué en c.
  Construis les BVH en **coordonnées monde** : sommets × `matrix_world` dans numpy, puis
  `BVHTree.FromPolygons(verts, tris, all_triangles=True)`. `overlap()` doit renvoyer une **liste vide**.
- Échantillonnage : (a) chaque engrènement, 50 positions sur un pas de dent ; (b) chaque tenon-rainure et
  chaque suiveur, 72 positions sur un cycle relatif complet ; (c) toutes les paires retenues par le
  pré-filtre, 240 valeurs de manivelle (120 uniformes sur [0, 1] an et 120 tirées au hasard sur [0, 76],
  graine 20260924). « Paires retenues » est défini au §5.8.
- Paires exclues : uniquement les objets d'un **même corps**, et les textes (objets FONT, voir étape 6). Tout
  le reste doit avoir un jeu physique : alésages +0,05, trous de plaques +0,05, rainure 1,1 pour un tenon de
  1,0. **Aucun contact de faces** entre corps différents : chaque extrémité d'arbre, de goujon ou de tenon
  s'arrête à ≥ 0,1 mm, ou dans un trou de jeu (§12 `shafts.rules`).

## 6. Arborescence à produire

```
spec/antikythera.json         # copie exacte du §12 (empreinte vérifiée)
am/__init__.py
am/spec.py                    # chargement, validation de structure, accès typé
am/kinematics.py              # Fraction, Willis, résolution globale, DDL, cibles, angles θ(t) en float64
am/expr.py                    # génère les expressions de drivers (≤ 255 car.) et les évalue en Python
am/involute.py                # profils à développante, jeu, phasage
am/outline.py                 # contours de roues : alésages, fenêtres, rayons de b1, anneau e4
am/crown.py                   # maillage des dents a1/q1 à partir des grilles d'enveloppe de la spec
am/layout.py                  # entraxes, recouvrements par couche, anneaux balayés, secteurs, zone a1
am/interference2d.py          # contrôle 2D par pas de dent
am/spiral.py                  # spirales à deux centres, table ψ→ρ
am/threemf.py                 # écriture 3MF minimale (zipfile + XML, unité millimeter)
am/report.py                  # rapport Markdown + HTML autonome
am/verify.py                  # CLI : python -m am.verify --stage {spec,kinematics,geometry,all} ; code ≠ 0 si échec
blender_scripts/bootstrap.py  # sys.path, lecture des arguments après "--"
blender_scripts/build.py      # scène, unités, collections, corps, pièces, matériaux → out/am.blend
blender_scripts/animate.py    # contrôleur, drivers, tables de correspondance, action de la manivelle
blender_scripts/dials.py      # cadrans avant/arrière, anneaux, aiguilles, graduations, textes
blender_scripts/materials.py
blender_scripts/check.py      # relecture des drivers, cycles, BVH, variétés → out/check.json
blender_scripts/export_print.py
blender_scripts/render.py
tests/test_*.py               # unittest (Python de Blender)
out/                          # am.blend, check.json, report.md, report.html, print/, renders/, logs/
README.md  DECISIONS.md  PROGRESS.md
```
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

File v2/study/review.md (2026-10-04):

# Revue adversariale de l'architecture

> Objet : `study/architecture.md` et son générateur (`tools/arch_*.py`, `tools/architecture.py`).
> Méthode : lecture, puis sondes Python sur `architecture.build(write=False)["items"]`. Aucun fichier modifié.
> Les chiffres « sonde » se reproduisent en quelques lignes avec `arch_geom.xy_gap` et `arch_geom.chain_shapes`.

## Verdict

L'arithmétique est juste : rapports 1:1, manivelle, masse, caisse, budget d'erreur recopié sans faute.
Mais le graphe des mouvements est incomplet : les sept copies de l'UAK Terre, le bloc du temps et le bloc lune
n'ont pas toutes leurs entrées. Et « 0 collision » vaut pour un modèle qui omet les pignons de moyeu, les roues
du carrousel, le prolongement des arbres jusqu'aux platines et les arbres consécutifs d'un même train.
Avec ces pièces, on trouve au moins 20 collisions réelles. L'architecture n'est pas prête pour la 3D.

## Défauts

### Bloquant

**B1. Les copies de l'UAK Terre n'ont pas d'entrée Y.**
- Quoi : le bus amène Y sur l'arbre d'entrée A0 du train moyen, pas sur l'axe de la tour. L'axe ne reçoit que
  la longitude moyenne de la planète (`#out`). Rien n'amène Y à la copie de l'UAK Terre empilée sur l'axe
  (`arch_layout.py:136-142`). Le module n'a donc pas son vecteur Terre.
- Preuve : `architecture.md:39-41` dit « empilés sur le même axe ». Distance A0 → axe de tour (sonde) :
  Vénus 132,3 ; Neptune 78,8 ; Mercure 67,8 ; Mars 48,8 ; Uranus 44,2 ; Jupiter 31,3 ; Saturne 30,9 mm.
  Aucun renvoi, aucune roue comptée.
- Correctif : trains moyens « revenants » (entrée et sortie coaxiales). Un module par couple suffit :
  pour Vénus, m 0,743 puis m 0,4 donnent deux entraxes de 71,0 mm. Le bus arrive alors sur un tube Y de l'axe.
  Sinon, un couple 1:1 A0 → axe par tour, dans un plan libre (+2 à 3 roues par tour).

**B2. Train J → Y : la roue de 144 traverse l'arbre Y.**
- Quoi : l'arbre a2 (−16,2 ; 16,7) porte la roue de 144 (r 36,5). L'arbre Y est à 23,25 mm. Y traverse
  forcément E4/A : il descend vers Y5 (E5) et monte vers Y4 et l'UAK maîtresse. Interpénétration : 15,3 mm.
  De même, la roue de 180 (r 45,5, sur a1) est à 40,75 mm de l'arbre a2.
- Preuve : sonde. La paire est masquée par les liens (`architecture.py:124`). La règle des arbres non
  consécutifs (`arch_geom.py:47-52`, `architecture.md:177-179`) ignore les arbres **consécutifs**.
- Correctif : inverser l'ordre des couples (10:83 d'abord, 31:180 en dernier). La 180 est alors sur Y, et
  l'avant-dernier arbre est à 52,75 mm de Y (> 36,5 + 2,5). Ajouter la règle « roue du couple k sur
  l'arbre k+1 contre l'arbre k+2 » au placement.

**B3. Moyeu Y4 : trois paires de pignons de 24 se chevauchent.**
- Quoi : les sept pignons couchés engrènent la couronne de 96 vers r 24. Un pignon de Ø 13 demande au moins
  34° d'écart. Écarts réels : Jupiter–Saturne 17,9° (corde 7,5 mm), Uranus–Neptune 24,0° (10,0 mm),
  Mercure–Mars 29,3° (12,1 mm).
- Preuve : ces pignons ne sont pas des objets. `arch_place.py:70-73` ne crée que la tringle au départ du
  moyeu ; `architecture.py:83-94` saute l'extrémité côté moyeu.
- Correctif : modéliser le pignon de départ ; imposer l'écart angulaire dans `place_out` ; ou deux couronnes
  Y4 superposées, sur deux couches.

**B4. Carrousel : les roues de 64 sont percées par les arbres voisins.**
- Quoi : roue de 64 (r de tête 16,5) ; arbre voisin (r 2) à 16,56 mm pour les écarts de 30°
  (Uranus–Neptune, Neptune–Dragon) : −1,94 mm. Écarts de 35° (Dragon–Lune, Lune–Mercure) : jeu 0,75 mm,
  sous le jeu de 1 mm. Tous les arbres partent de E1 T1 : l'arbre dont la roue est plus haute traverse le
  plan de l'autre, quel que soit l'ordre.
- Preuve : `arch_layout.py:94, 172-173`. Les roues de 64 ne sont pas modélisées ; le bloc `pile` est lié à
  tous les `car_*`.
- Correctif : écart ≥ 36° (9 × 40° tient sur le cercle) ou rayon de carrousel ≥ 40 mm. Modéliser les roues.

**B5. La boîte de Laplace ne contient pas ses trains.**
- Quoi : le seul train de Ganymède (167:131 · 10:23 · 29:115) demande une enveloppe de r 75,1 mm
  (`chain_shapes`). Le bloc fait r 66 (`arch_layout.py:126, 167`). Il doit aussi loger ν (r min 60,0),
  Callisto (50,3), deux doubleurs et deux différentiels, sur 30 mm d'épaisseur.
- Correctif : bloc sur deux sous-étages (E1 T2 + pile), ou train de Ganymède sans couple 167:131.
  Grossir le bloc sur place le fait sortir de la platine (x = −230 < −223).
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

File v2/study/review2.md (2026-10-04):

# Seconde revue : vérification de la version 2

> Objet : `study/architecture.md` (version 2), `spec/architecture.json` et `tools/arch_*.py`.
> Méthode : lecture du code ; `python3 architecture.py --check` (59 s, reproduit) ; sondes Python sur les
> `items` de `architecture.json` ; un recontrôle strict des collisions (liens par id exact, groupe de tour,
> groupe de renvoi) ; une seule relance du placement, avec la reprise par pignon fou imposée. Aucun fichier
> du projet modifié.

## Verdict

La version 2 corrige l'essentiel de la v1. Toutes les entrées existent. B2, B3, B4, I4, I6, I9 et I10 sont réglés.
Le vérificateur est sain pour les pièces modélisées : le recontrôle strict ne trouve que 2 vrais recouvrements cachés.
Mais la reprise 1:1 directe a introduit une erreur de sens : dans 4 tours, la planète tourne à l'envers de la Terre.
Avec un pignon fou, Vénus et Neptune ne se placent plus. Les couples d'entrée du bloc Lune changent les rapports.
L'arbre de précession n'atteint pas le bloc du temps. Pas encore prêt pour la 3D : corriger N1 à N4 d'abord.

## Suivi des défauts de la première revue
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

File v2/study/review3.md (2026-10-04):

# Troisième revue : vérification de la version 3

> Objet : `study/architecture.md` (version 3), `spec/architecture.json` et `tools/arch_*.py`.
> Méthode : lecture du code ; `python3 architecture.py --check` (64 s, reproduit) ; sondes Python sur les `items`
> (sens par tour, tenons, entraxes, recontrôle strict par id exact, plans libres pour les couples d'entrée,
> plus grande roue libre par demi-bloc). Aucun fichier du projet modifié, sauf celui-ci.

## Verdict

La version 3 corrige vraiment N1, N3, N4 et N6 à N10. Le sens L/Y vaut +1 dans les 7 tours, comme `trains.json`.
`--check` est reproduit : 368 objets, 0 collision, 507 roues. Le recontrôle strict ne cache aucun recouvrement réel.
Deux points restent ouverts. N2 n'est corrigé que sur le papier : les couples 1:1 de L et de ϖ n'ont aucun plan libre.
N5 l'est en partie : le budget du bloc Lune oublie deux différentiels (78 mm pour 60). Pas de bloquant.
La 3D peut commencer pour les tours, E4, E3 et E1 ; le bloc Lune doit être repris d'abord.
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

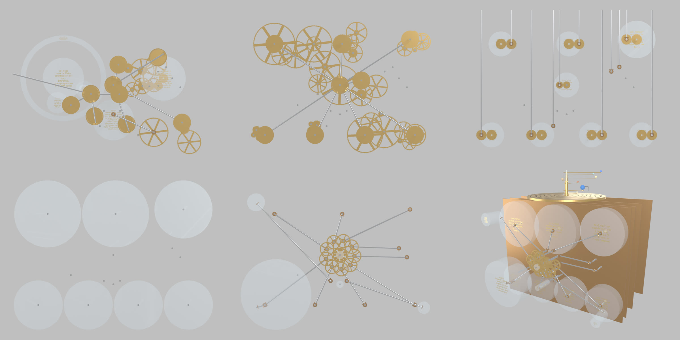
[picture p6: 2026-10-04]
docs/v2/img/etages.jpg

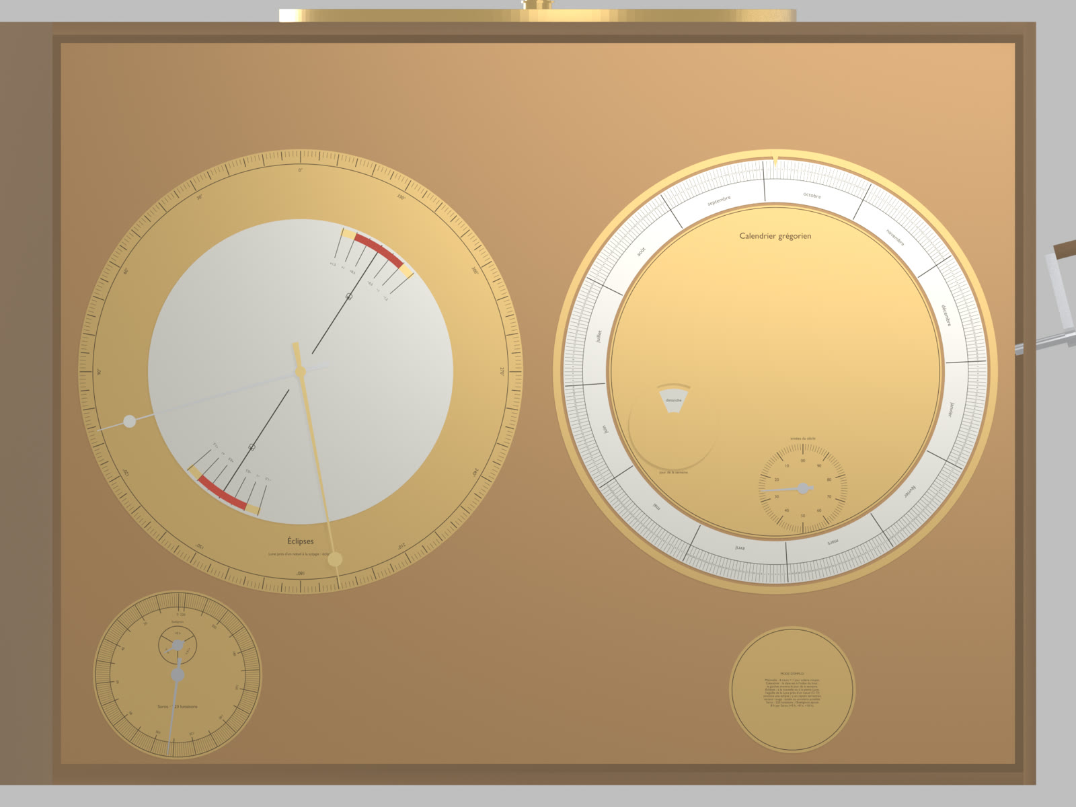
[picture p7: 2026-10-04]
v2/study/img/back.jpg

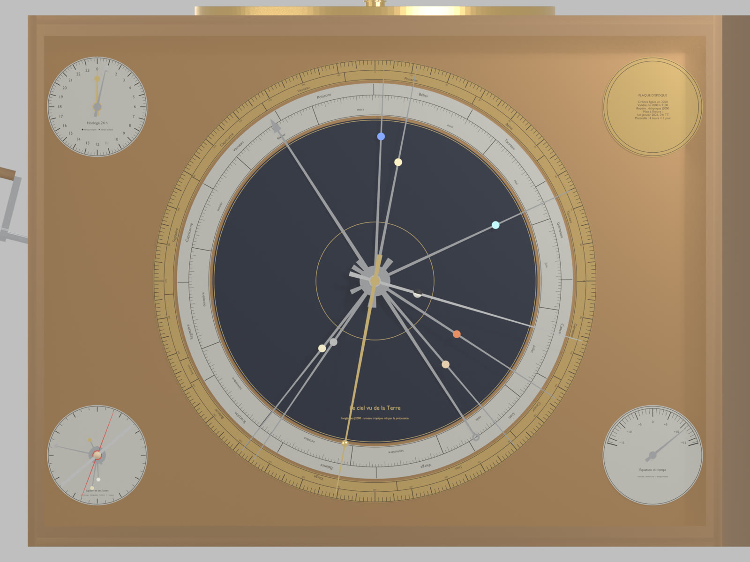
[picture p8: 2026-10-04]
docs/v2/img/front.jpg

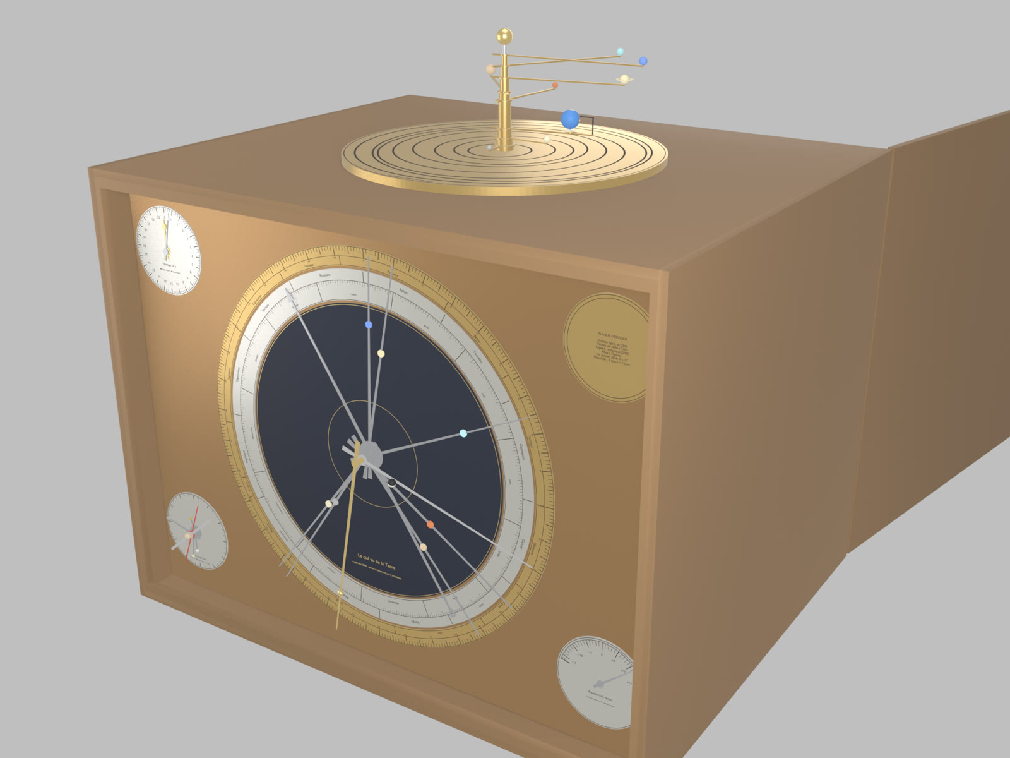
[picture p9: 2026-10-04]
docs/v2/img/front34.jpg

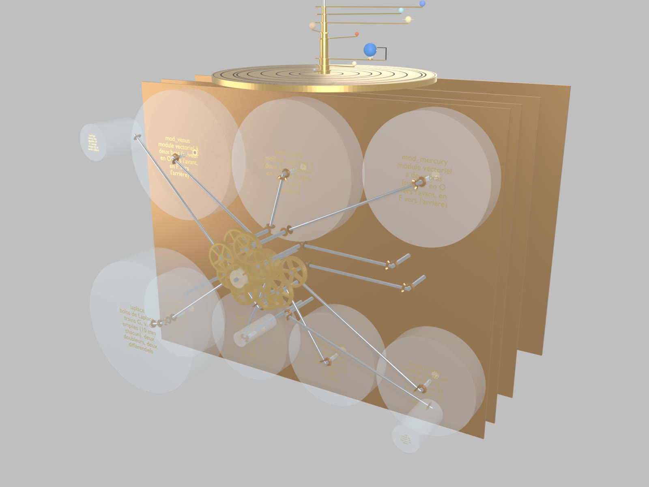
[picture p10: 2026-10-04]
v2/study/img/interior.jpg

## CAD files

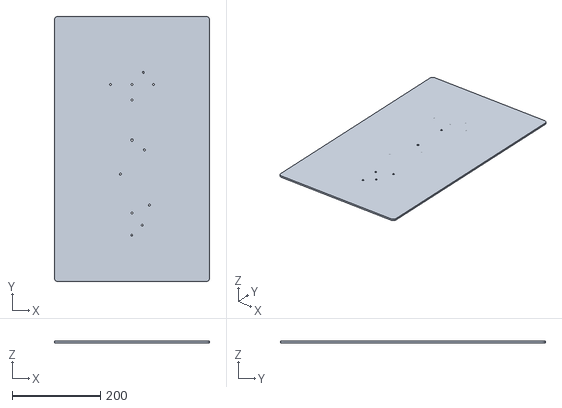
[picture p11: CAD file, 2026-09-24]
build/out/print/fdm_x2/main_plate.stl
352.0 x 600.0 x 4.00

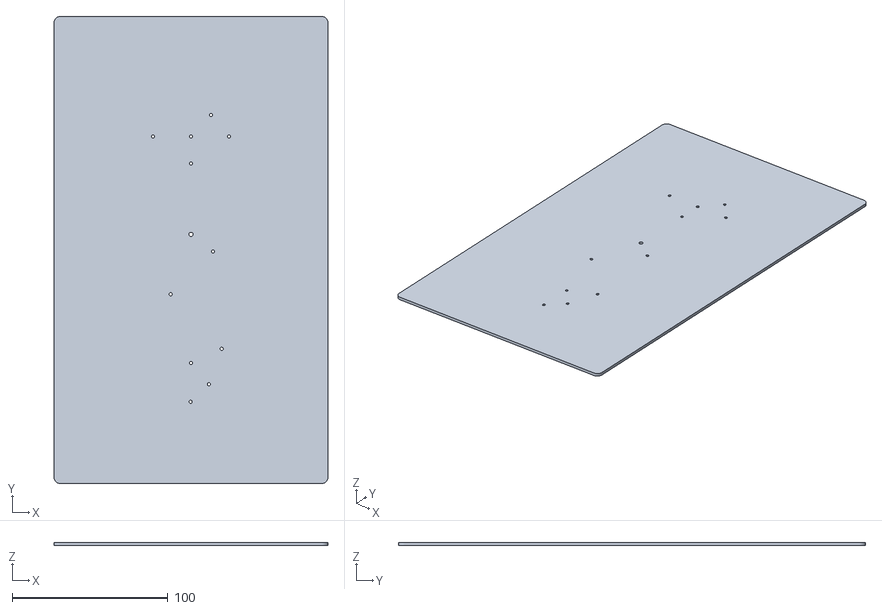
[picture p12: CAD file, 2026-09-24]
build/out/print/resin_x1/main_plate.stl
176.0 x 300.0 x 2.00

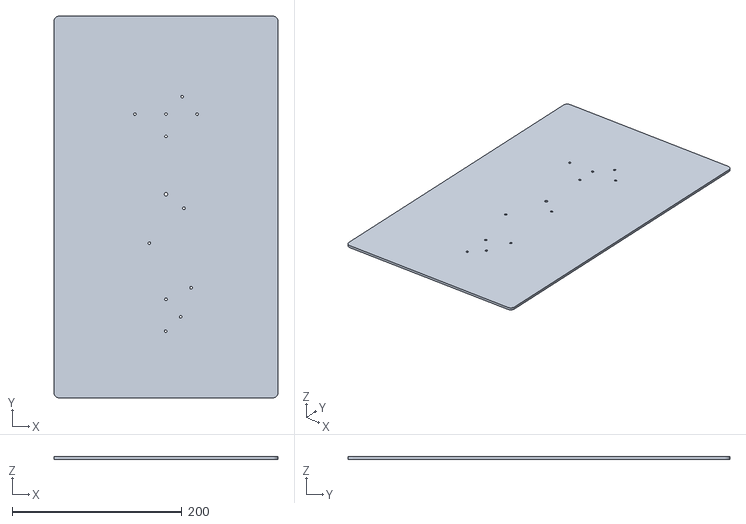
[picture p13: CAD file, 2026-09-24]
build/out/print/resin_x1_5/main_plate.stl
264.0 x 450.0 x 3.00

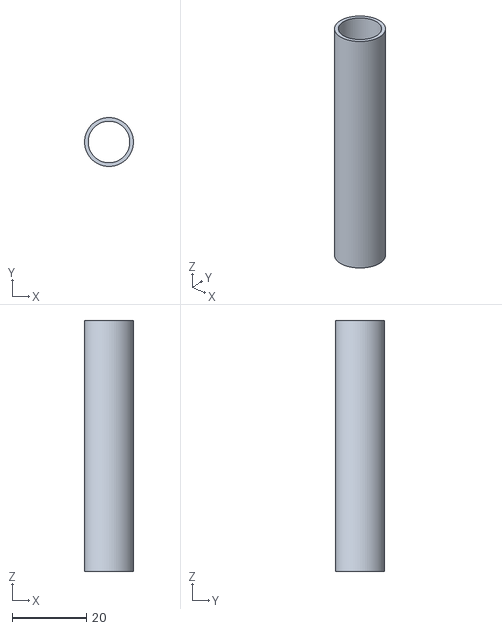
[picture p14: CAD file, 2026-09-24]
build/out/print/fdm_x2/t_mercury.stl
13.2 x 13.2 x 67.7

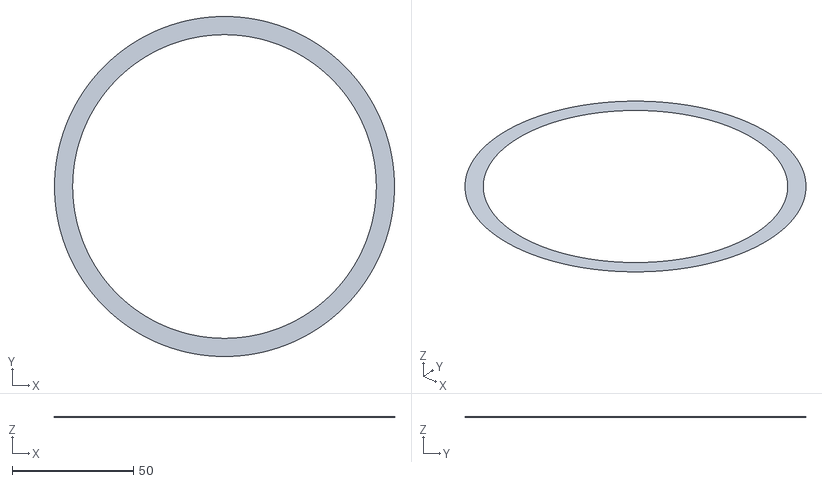
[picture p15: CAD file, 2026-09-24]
build/out/print/resin_x1/zodiac_ring.stl
140.0 x 140.0 x 0.1

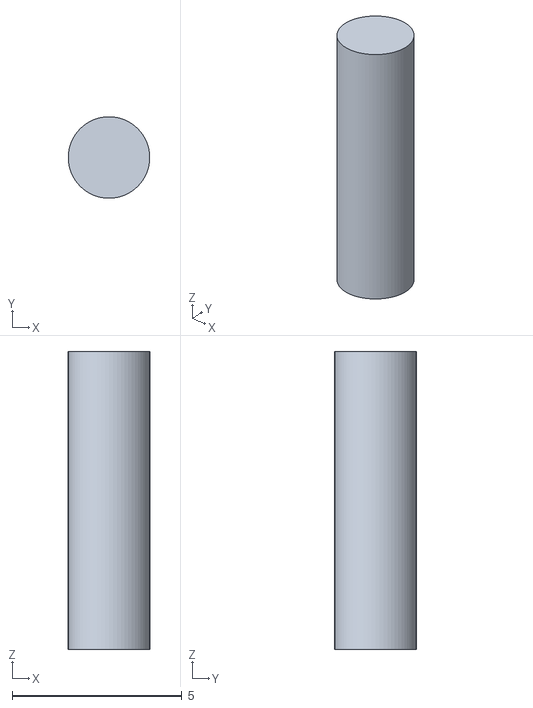
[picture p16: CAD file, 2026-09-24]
build/out/print/resin_x1_5/stud_spB.stl
2.40 x 2.40 x 8.77

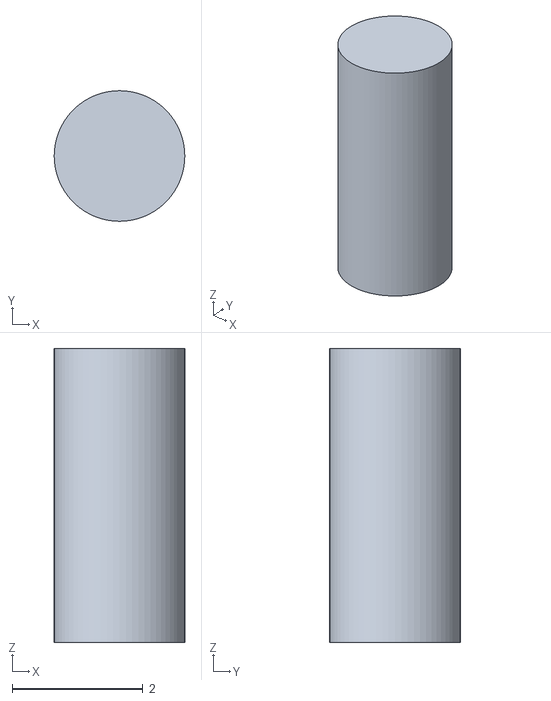
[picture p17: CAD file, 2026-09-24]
build/out/print/fdm_x2/pin_mercury.stl
2.00 x 2.00 x 4.50

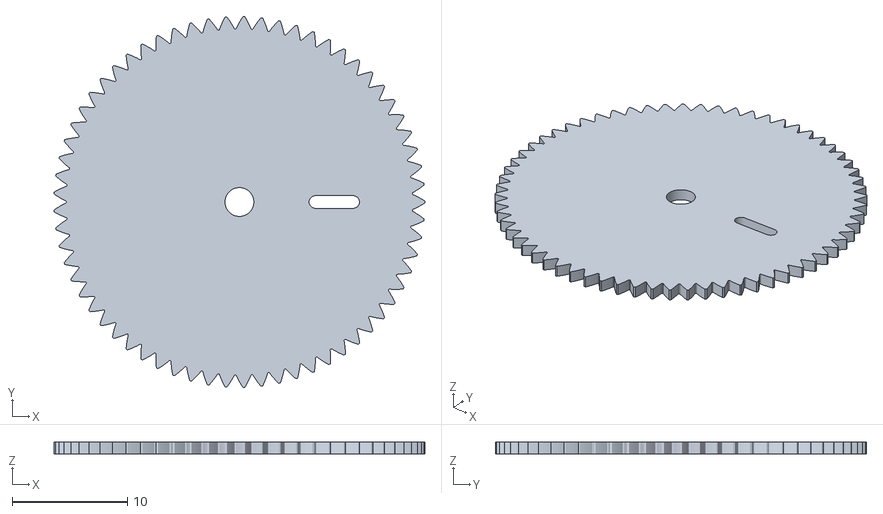
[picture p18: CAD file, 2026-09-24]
build/out/print/resin_x1/ju65s.stl
32.1 x 32.2 x 1.00

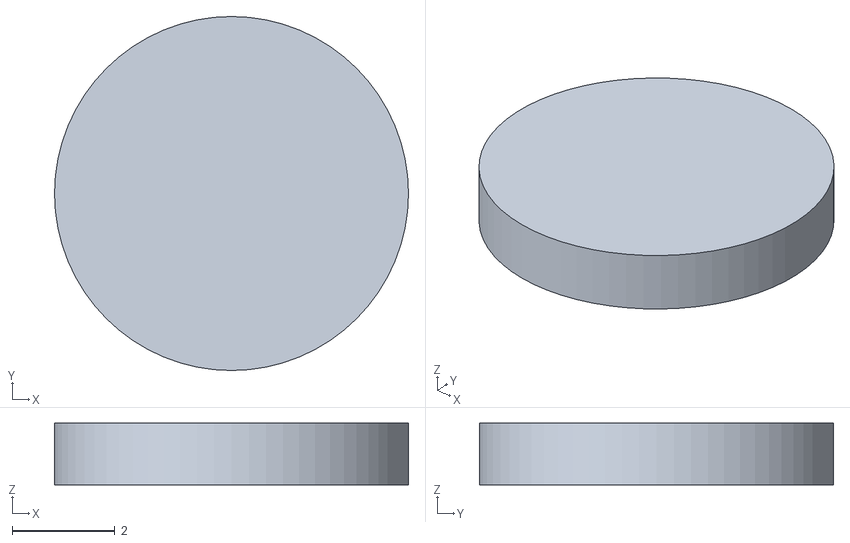
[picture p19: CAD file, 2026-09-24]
build/out/print/resin_x1_5/boss_k.stl
6.90 x 6.90 x 1.20

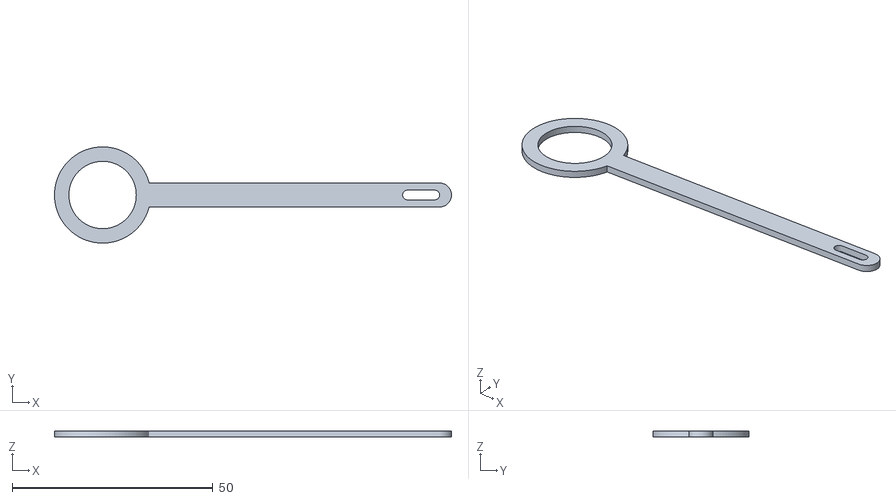
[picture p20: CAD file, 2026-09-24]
build/out/print/fdm_x2/true_sun_follower.stl
99.0 x 24.0 x 1.60

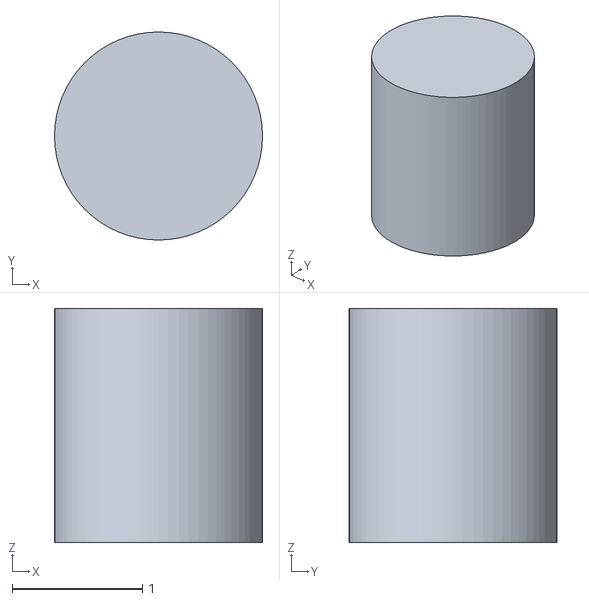
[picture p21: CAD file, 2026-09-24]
build/out/print/resin_x1/stud_vn26.stl
1.60 x 1.60 x 1.80

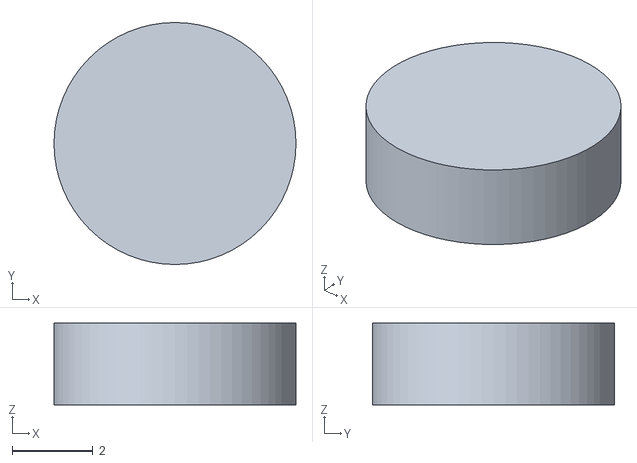
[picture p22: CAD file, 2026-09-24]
build/out/print/resin_x1_5/standoff_2.stl
6.00 x 6.00 x 2.02

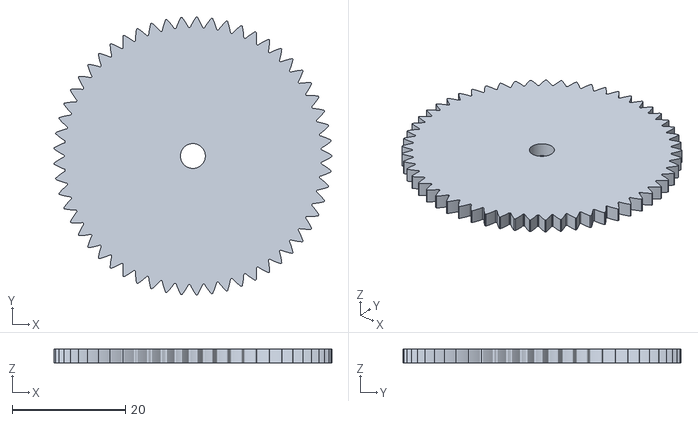
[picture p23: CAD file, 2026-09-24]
build/out/print/fdm_x2/n3.stl
49.2 x 49.2 x 2.40

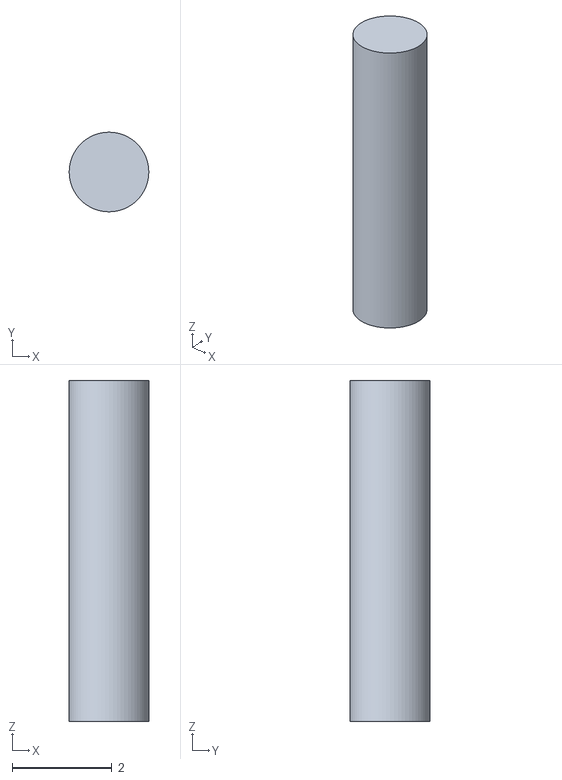
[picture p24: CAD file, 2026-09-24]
build/out/print/resin_x1/stud_me40.stl
1.60 x 1.60 x 6.85

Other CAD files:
build/out/print/resin_x1_5/k2.stl
build/out/print/fdm_x2/b3.stl
build/out/print/resin_x1/front_plate.stl
build/out/print/resin_x1_5/case_cover_back.stl
build/out/am.blend
build/out/am_atelier.blend
build/out/print/fdm_x2/a1.stl
build/out/print/fdm_x2/a_shaft.stl
build/out/print/fdm_x2/antikythera.3mf
build/out/print/fdm_x2/b0.stl
build/out/print/fdm_x2/b1.stl
build/out/print/fdm_x2/b1_hub.stl
build/out/print/fdm_x2/b2.stl
build/out/print/fdm_x2/b_hub.stl
build/out/print/fdm_x2/back_plate.stl
build/out/print/fdm_x2/boss_ju43.stl
build/out/print/fdm_x2/boss_k.stl
build/out/print/fdm_x2/boss_ma71.stl
build/out/print/fdm_x2/boss_sa68.stl
build/out/print/fdm_x2/c1.stl
build/out/print/fdm_x2/c2.stl
build/out/print/fdm_x2/cal1.stl
build/out/print/fdm_x2/calendar_marks.stl
build/out/print/fdm_x2/calendar_ring.stl
build/out/print/fdm_x2/callippic_dial.stl
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

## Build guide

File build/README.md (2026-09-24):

# Antikythera Mechanism: functional reconstruction in Blender 5.2

This project builds the mechanism from `spec/antikythera.json`, the single source of truth. It works in five stages:

- it proves the kinematics with exact fractions: rank 44, one degree of freedom, and every target exact;
- it generates conjugate 30° involute gearing, the plates, dials and case;
- it assembles an animated Blender scene driven by a single crank;
- it checks that no part penetrates another over the whole range of motion;
- it exports print files, renders images and an animation, and writes a report.

## Environment

```sh
PY=/Applications/Blender.app/Contents/Resources/5.2/python/bin/python3.13   # numpy 2.3.4
BL=/Applications/Blender.app/Contents/MacOS/Blender                         # Blender 5.2.2 LTS
cd <this folder>
```

The `am/` package never imports `bpy`, so it can be tested outside Blender. Only `blender_scripts/` uses Blender.

## Re-run everything (one command per step)

| Step | Command | Output |
|---|---|---|
| 0 spec fingerprint | `"$PY" -m am.verify --stage spec` | `out/verify_spec.json` |
| 1 exact kinematics | `"$PY" -m unittest discover -s tests -v && "$PY" -m am.verify --stage kinematics` | DOF, rates, targets |
| 2 2D geometry | `"$PY" -m am.verify --stage geometry` | meshes, 2D interference, pre-filter, cosmos; writes `out/prefilter_pairs.json` |
| 3 driver expressions | `"$PY" -m am.verify --stage expr` | expression errors < 1e-9 rad |
| 1-3 together | `"$PY" -m am.verify --stage all` | `out/verify_all.json` |
| 4 Blender build | `"$BL" -b --factory-startup --python-exit-code 1 -P blender_scripts/build.py` | `out/am.blend`, `out/build_report.json` |
| 5 3D checks | `for m in static meshes pins spiral texts sanity; do "$BL" -b --factory-startup --python-exit-code 1 -P blender_scripts/check.py -- $m; done` | `out/check_<mode>.json` |
| 5 BVH pairs (8 batches) | `for i in 0 1 2 3 4 5 6 7; do "$BL" -b --factory-startup --python-exit-code 1 -P blender_scripts/check.py -- pairs $i 8; done` | `out/check_pairs_<i>.json` |
| 5 merge | `"$BL" -b --factory-startup --python-exit-code 1 -P blender_scripts/check.py -- merge` | `out/check.json` |
| 7 print | `"$BL" -b --factory-startup --python-exit-code 1 -P blender_scripts/export_print.py` | `out/print/<profile>/*.stl`, `antikythera.3mf`, `print_report.json` |
| 8 stills (Cycles Metal) | `"$BL" -b --factory-startup --python-exit-code 1 -P blender_scripts/render.py -- stills warmup cycles && "$BL" -b --factory-startup --python-exit-code 1 -P blender_scripts/render.py -- stills all cycles` | `out/renders/{front34,front,back,exploded}.png` |
| 8 animation frames | `"$BL" -b --factory-startup --python-exit-code 1 -P blender_scripts/render.py -- frames 1 120` (then 121-240, 241-360, 361-480) | `out/renders/frames/f_####.png` |
| 8 encode + verify | `"$BL" -b --factory-startup --python-exit-code 1 -P blender_scripts/render.py -- encode && "$BL" -b --factory-startup --python-exit-code 1 -P blender_scripts/render.py -- verify` | `out/renders/antikythera.mp4` (480 frames) |
| 9 report | `"$PY" -m am.report` | `out/report.md`, `out/report.html` |

Blender logs go to `out/logs/`.

## Using `out/am.blend`

- `AM_Controller["crank"]` is the crank position in years; 1 year = 1 turn of b1. A linear action moves it from 0 to 4 years over frames 1–481, with linear extrapolation.
- `AM_Controller["patina"]` blends from new bronze (0) to museum patina (1).
- Every body is an Empty `B_<id>` whose rotation is a **simple-expression driver**. The file therefore animates without allowing Python scripts.
- Every part is a child of its body Empty, modelled in that body's local frame. Parts carry these custom properties: `status`, `role`, `teeth`, `module`, `body` and `sources`.
- `obj.color` shows the status colour; use Solid/Object colour mode to see it.
- Collections: `AM_SURVIVING`, `AM_RECONSTRUCTED`, `AM_HYPOTHETICAL`, `AM_STRUCTURE`, `AM_DIALS`, `AM_CASE` and `AM_HELPERS`. The case covers are hidden.

## Layout

```
spec/antikythera.json    spec (fingerprint 18934c80…86b3)
am/spec.py               loading, fingerprint, structural validation
am/kinematics.py         Fraction solver (Willis), DOF, targets, angle laws theta(t)
am/expr.py               driver expressions + restricted evaluator
am/involute.py           30° involute teeth, backlash, contact ratio, phasing forest
am/outline.py            circles (clearance side counts), slots, arms, windows, gear loops
am/crown.py              a1 / q1 crown teeth from the envelope grids
am/spiral.py             two-centre spirals, grooves, cells, psi->rho table
am/layout.py             catalogue of all 228 parts (islands extruded along z or x), print profiles
am/regions.py            conservative swept-region collision pre-filter
am/interference2d.py     2D tooth interference over one pitch
am/geomcheck.py          'geometry' stage (+ cosmos checks)
am/threemf.py            minimal 3MF writer/reader
am/report.py             Markdown + HTML report
am/verify.py             CLI
blender_scripts/         bootstrap, build, animate, materials, meshing, dials, check, export_print, render
tests/                   unittest suites (Blender's Python)
```

`PROGRESS.md` records what happened at each step. `DECISIONS.md` lists the choices made where the spec is silent.

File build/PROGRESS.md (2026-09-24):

# PROGRESS

| Step | State | Notes |
|---|---|---|
| 0 spec | GREEN | `spec/antikythera.json` written in 5 chunks; canonical SHA-256 `18934c80…86b3`, 24/24 section fingerprints OK. |
| 1 kinematics | GREEN | 45 unknowns, 44 equations (37 Willis, 4 pin-slot, 3 followers), rank 44, DOF 1, 0 inconsistent, 45 rates = spec, 22/22 targets exact. |
| 2 geometry 2D | GREEN | 37/37 meshes: centre distances exact (max err 6e-11 mm), eps min 1.324, face overlap min 0.50; 2D interference 0 penetration, backlash near line of centres 0.0130 mm; 28 phasing components; pre-filter 228 parts / 4251 z-overlapping pairs / 0 conflicts / 83 intended contacts / 168 retained pairs; a1 keep-out OK; follower sectors free; cosmos checks OK (apogee 65.500 deg, anomaly 6.5796 deg). |
| 3 expressions | GREEN | 47 body drivers, max 120 chars, max error 6.7e-13 rad over 200 samples in [-50, 50]. |
| 4 Blender build | GREEN | `out/am.blend`: 228 mesh parts, 31 FONT texts, 49 empties; 52 drivers valid/simple/untruncated; all meshes closed, manifold, contiguous, volume = area x thickness (max rel err 3e-13). Build 3 s. |
| 5 3D check | GREEN | readback max 6.0e-7 rad (50 values); cycles Metonic/Olympiad/Callippic/Saros closed (max 3e-7 rad); crank F-curve 0/0.5/4.0; BVH: 39 meshes x 50 positions, 9 pin/follower/slider cycles x 72, 168 pairs x 240 cranks -> 0 overlaps. BVH sanity test detects known intersections and a mis-phased gear. |
| 6 dials & case | GREEN | dials are catalogue parts (rings, marks, spirals, pointers, sliders, markers) + 31 Greek FONT texts (no missing glyph); spirals follow rho(psi) within 1.2e-4 mm (500 values); texts >= 0.15 mm in z from overlapping moving parts. |
| 7 print | GREEN | resin_x1 / resin_x1_5 / fdm_x2: 228 STL each (unparented body-local copies, `global_scale` = scale) + one 3MF (228 closed objects, re-read OK); 2D check with the profile backlash OK (near-centre backlash 0.0217 / 0.0347 / 0.0868 mm); STL re-import sizes within 1e-3; walls >= min_wall everywhere; fragile tips listed (h2, p2; 8 gears at fdm_x2); oversize parts listed (b1 at fdm_x2 is 260 mm). ~11 s per profile. |
| 8 renders | GREEN | Cycles Metal (Apple M4 GPU): warm-up + 4 stills 1920x1080, 256 samples, OIDN on GPU (~1 min each). EEVEE: 480 PNG frames 1280x720 in 4 batches (~0.8 s/frame), encoded once via the sequencer; `movieclips.load(...).frame_duration == 480`. |
| 9 report | GREEN | `out/report.md` + `out/report.html`: 22 trains, cosmos checks, DOF/rank, every check with numbers, modules and centre distances, parts by status, FONT texts, print table, unresolved defaults, decisions, fallbacks (none). All 10 criteria GREEN. |

Final re-run of the full 3D check suite on the final `out/am.blend`: `out/check.json` summary ok = True (0 overlaps on all samples).

## Problems met and fixes
- `layout.gear`: b1/b0 are not in the spur forest -> phase 0 (spec 5.3).
- Pre-filter: slider-pin band vs dial rim reported as overlap because hole-less polygon distance was used -> island distance now honours holes (an island lying in a hole).
- Volume check: thin strips (0.4 mm wide) failed at 1.5e-5 because the contour area was computed on float64 coordinates while vertices are stored in float32 -> area now computed on the float32 contour (same treatment as z in spec 5.5).
- Print profiles: hole radii that were constants (hubs, disks, levers, rings, plate centre holes) now use `Profile.hole(r_inner, r_spec)` so every bore/hole is regenerated with `bore_clearance_mm`; scholarly geometry unchanged (pre-filter re-run: 0 conflicts).
- STL export in an empty factory scene: removed temporaries left `None` entries in the view-layer object list -> deselect via `scene.objects` after `view_layer.update()`.
- Renders: first previews too dark/patinated (metallic bronze reflecting a black world) -> studio-grey world, patina 0.06 for stills, darker engraving material for dial marks, case hidden for the 3/4, dial and exploded views.
- Animation batch loop: zsh does not word-split and aborts on an empty glob -> loops run under `bash -c`.

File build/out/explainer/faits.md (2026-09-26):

# Fiche de faits vérifiés : « Comment lire la machine d'Anticythère »

Fiche préparée le 25 septembre 2026 pour la vidéo explicative (voix off en français) et la page web interactive.
Règle d'honnêteté : chaque énoncé porte sa source et un niveau de confiance (haute / moyenne / faible).
Pour la voix off, les formules prudentes (« probablement », « selon… ») sont à garder telles quelles.

**Trois garde-fous à respecter dans tout le récit**

- **HYPOTHÉTIQUE.** Les trains d'engrenages des planètes, l'aiguille du Dragon (nœuds de la Lune) et le « Soleil vrai » de notre modèle suivent la reconstruction de Freeth et al. 2021. Aucune pièce de ces engrenages n'a survécu avec certitude.
- **CALCULÉ PAR NOTRE MODÈLE.** Les glyphes d'éclipse que nous affichons sont calculés par notre modèle, dont l'époque de départ n'est pas calibrée. Ils ne reproduisent pas les glyphes de l'original, sauf si une source historique est citée.
- **PAS UN INSTRUMENT DE NAVIGATION.** Le seul lien avec la mer passe par le calendrier du ciel (levers et couchers d'étoiles) qui indiquait la saison de navigation. Voir la partie 5.

---

## 1. La découverte

| # | Fait | Source | Confiance |
|---|---|---|---|
| 1.1 | Au printemps 1900, des pêcheurs d'éponges de l'île de **Symi** s'abritent d'une tempête près d'Anticythère. Leur capitaine est Dimitrios Kontos. Le plongeur Elias Stadiatis découvre l'épave par **40 à 50 m** de fond. | WHOI, *Antikythera shipwreck* ; Wikipédia *Antikythera wreck* | haute |
| 1.2 | Les objets sont remontés en **1900-1901** par le Service archéologique grec, avec les pêcheurs d'éponges de Symi et la Marine royale grecque. C'est la première grande fouille archéologique sous-marine. Une deuxième campagne a lieu en **1976** avec la *Calypso* de Cousteau. Les recherches continuent depuis 2012. | Musée national archéologique d'Athènes (NAM), exposition « The Antikythera Shipwreck » et site *antikythera-mechanism.namuseum.gr* ; WHOI | haute |
| 1.3 | Le mécanisme est remarqué en **1902** au Musée national d'Athènes. Sur un bloc de bronze corrodé, on voit une roue dentée et des inscriptions grecques. | Jones 2020 (ISAW Papers 17) ; Wikipédia | haute |
| 1.4 | Le naufrage date d'environ **60 ± 10 av. J.-C.** Les céramiques pointent vers le milieu du Ier siècle av. J.-C. Un petit trésor de 36 tétradrachmes d'argent de Pergame et d'Éphèse contient des pièces allant jusqu'à environ 76-67 av. J.-C., mais aucune pièce frappée après la reprise de 58 av. J.-C. Le NAM donne « entre 75 et 50 av. J.-C. ». | Jones 2020 ; NAM | haute |
| 1.5 | La cargaison est un chargement de luxe. On y trouve des bronzes originaux (l'**Éphèbe d'Anticythère**, la tête du « **Philosophe** »), des statues de marbre de dieux et de héros, des lits de bronze, des bijoux en or, de la verrerie, des amphores et des lampes. Le cargo, d'environ 300 tonnes, se dirigeait **très probablement vers l'Italie**. Il a coulé au nord-est d'Anticythère. | NAM (*antikythera-mechanism.namuseum.gr/en/archaeologist/*) | haute (destination : « probablement ») |
| 1.6 | Il reste **82 fragments**, soit environ **un tiers** de l'original. Ils contiennent **30 roues dentées** en bronze. La machine était logée dans un **boîtier en bois**, avec une plaque de métal à l'avant et une à l'arrière. | Freeth et al. 2021 (*Sci. Rep.* 11:5821) ; NAM | haute |
| 1.7 | **Date de fabrication.** L'écriture des inscriptions situe l'objet entre la fin du IIIe et le milieu du Ier siècle av. J.-C. (la paléographie n'est précise qu'à un siècle près). Le cadran des éclipses a été calculé à partir de **205 av. J.-C.** Le naufrage (vers 60 av. J.-C.) fixe la limite basse. La fabrication se situe donc entre environ 205 et 60 av. J.-C. Le musée indique « IIe siècle av. J.-C. », et Freeth et al. 2006 « vers la fin du IIe siècle av. J.-C. ». | Jones 2020 ; Freeth et al. 2006 (*Nature* 444) ; NAM | haute pour la fourchette ; date exacte inconnue |
| 1.8 | **Lieu de fabrication inconnu.** L'hypothèse de Rhodes repose sur la fête des Halieia sur le cadran des Jeux et sur Cicéron, qui décrit une « sphère » de Posidonios à Rhodes. Le calendrier corinthien et les jeux Naa de Dodone suggèrent un client en Épire (Grèce du Nord-Ouest). Syracuse, la ville d'Archimède, a aussi été évoquée en 2008. | Freeth et al. 2008 ; Iversen 2017 ; Jones 2017, 2020 ; Freeth & Jones 2012 | moyenne |

## 2. Lire la FACE AVANT

| # | Fait | Source | Confiance |
|---|---|---|---|
| 2.1 | La face avant porte **un seul grand cadran** entouré de deux anneaux gradués. L'anneau **extérieur** est le **calendrier égyptien** de **365 jours** : 12 mois de 30 jours plus 5 jours « épagomènes », avec les noms grecs des mois égyptiens (sont conservés ΠΑΧΩΝ, ΠΑΥΝΙ et ΕΠΕΙΦ). L'anneau **intérieur** est le **zodiaque** : 12 signes de 30° (sont conservés la Vierge, la Balance appelée ΧΗΛΑΙ, « les Pinces », le Scorpion et le Sagittaire). Environ un cinquième de chaque échelle survit. | Bitsakis & Jones 2016 (*Almagest* 7.1, IAM 3) | haute |
| 2.2 | L'anneau égyptien était **amovible**. Une cheville placée au dos s'enfonçait dans l'un des trous percés sous l'anneau. L'année égyptienne de 365 jours glisse d'environ un jour tous les 4 ans par rapport aux saisons : on la recalait sur le zodiaque. Le **nombre de trous est débattu** : 365 selon Bitsakis & Jones 2016 et Freeth 2021 ; environ 354-355 (une année lunaire) selon Budiselić et al. 2020 et Woan & Bayley 2024. | Bitsakis & Jones 2016 ; Woan & Bayley 2024 (arXiv:2403.00040) | haute (amovible) ; moyenne (nombre de trous) |
| 2.3 | Des aiguilles partant du centre montraient les longitudes du **Soleil**, de la **Lune** et des **cinq planètes**. L'inscription du couvercle arrière (BCI) décrit un « **cosmos** » en cercles. Les planètes y sont marquées par de « **petites sphères** » et le Soleil par une « **petite sphère dorée** », avec un « rayon » et une « aiguille ». | Bitsakis & Jones 2016 ; Freeth & Jones 2012 ; Freeth et al. 2021 | haute (le texte) ; forme exacte de l'affichage : hypothétique |
| 2.4 | **Noms des planètes** dans la BCI : Stilbôn (Mercure, « l'étincelant ») ; Phôsphoros, « astre d'Aphrodite » (Vénus) ; Pyroeis, « astre d'Arès » (Mars) ; Phaethôn, « astre de Zeus » (Jupiter) ; Phainôn, « astre de Kronos » (Saturne). L'ordre part de la Terre : **Lune, Mercure, Vénus, Soleil, Mars, Jupiter, Saturne**. | Freeth & Jones 2012 ; Freeth et al. 2021 | haute |
| 2.5 | L'inscription du couvercle avant (FCI) décrit, planète par planète, les événements du cycle synodique et les intervalles en jours qui les séparent. Elle mentionne les **stations** (*stêrigmos*, arrêt apparent avant un recul) et la **plus grande élongation** (Mercure, Vénus). On y a lu **462** dans la section de Vénus (289 cycles en 462 ans) et **442** dans celle de Saturne (427 cycles en 442 ans). | Freeth et al. 2021 ; Freeth & Jones 2012 | haute |
| 2.6 | **Aucun engrenage de planète n'a survécu avec certitude.** Les planètes, l'aiguille des nœuds (« Dragon ») et le Soleil vrai de notre modèle suivent la reconstruction HYPOTHÉTIQUE de Freeth et al. 2021. Les indices matériels sont minces : des piliers et des paliers sur la grande roue b1, et une roue de 63 dents dans le fragment D, attribuée à Vénus. Pour l'aiguille des nœuds, les auteurs écrivent : « aucune preuve physique directe ». | Freeth et al. 2021 | haute |
| 2.7 | **Rétrogradation.** Vues de la Terre, les planètes semblent s'arrêter, puis reculer quelque temps. Mars, Jupiter et Saturne reculent autour de l'opposition ; Mercure et Vénus autour de la conjonction inférieure. La FCI parle bien de ces « stations ». La reconstruction les reproduit par des épicycles à « goupille et fente ». | Freeth & Jones 2012 ; Freeth et al. 2021 | haute (texte) ; mécanisme hypothétique |
| 2.8 | **L'aiguille de la Lune** fait un tour par mois, **à vitesse variable**. Un système « goupille et fente » (deux roues superposées dont les axes sont décalés) reproduit la théorie lunaire d'**Hipparque**. Ces pièces **survivent**. | Freeth et al. 2006 | haute |
| 2.9 | **La boule des phases** est une petite boule **moitié noire, moitié blanche** (souvent argentée dans les reconstructions). Elle tourne au bout de l'aiguille lunaire, entraînée par la **différence Lune moins Soleil**. Elle montre sa face noire à la **nouvelle lune** (aiguilles de la Lune et du Soleil superposées) et sa face blanche à la **pleine lune** (aiguilles opposées). | Freeth & Jones 2012 (d'après Wright 2006) ; Freeth et al. 2021 | haute |
| 2.10 | **Les couleurs des planètes sont inconnues.** Freeth & Jones proposent des pierres d'après un papyrus astrologique des IIe-IIIe siècles apr. J.-C. : Soleil or, Lune argent, Saturne obsidienne, Mars onyx rouge, Vénus lapis-lazuli, Mercure turquoise, Jupiter cristal blanc. **Nos couleurs sont modernes**, choisies pour la lisibilité. | Freeth & Jones 2012 | haute |
| 2.11 | **Le parapegme.** Deux plaques, au-dessus et au-dessous du cadran, portaient une liste de **42 événements annuels** : solstices, équinoxes, entrée du Soleil dans chaque signe, et une trentaine de **levers et couchers d'étoiles**. Le texte était réparti en **4 colonnes, une par saison**. Des **lettres gravées sur l'échelle du zodiaque** renvoient à ces lignes. Quand l'aiguille du Soleil atteint une lettre, on lit la ligne qui porte la même lettre. Le 0° du Bélier (équinoxe de printemps) était **en haut** du cadran. | Bitsakis & Jones 2016 | haute |
| 2.12 | **Sept noms d'astres sont conservés** : Sirius (« le Chien »), Arcturus, les Pléiades, les Hyades, la Lyre, l'Aigle, Orion. Lignes lues : « Λ — Les Hyades se couchent le soir. 24 » ; « Ξ — La Pléiade se lève le matin. 17 » ; « Ο — L'Hyade se lève le matin. 25 » ; « Ρ — L'Aigle se lève le soir » ; « Σ — Arcturus se couche le matin. 10 ». Deux autres lignes sont partiellement restituées : « Orion [se lève le matin] » et « Le Chien [se lève le matin] ». Le nombre final semble indiquer le degré dans le signe. | Bitsakis & Jones 2016 | haute (mots conservés) ; moyenne (restitutions) |
| 2.13 | **À quoi servaient ces dates.** Le « lever du matin » d'une étoile est sa première réapparition à l'aube ; le « coucher du soir » est sa dernière visibilité au crépuscule. Dans la tradition grecque (Euctémon, Eudoxe, Callippe, Hipparque), ces dates marquaient les **saisons** et s'accompagnaient de notes météo. Exemple tiré du parapegme de Géminos : « selon Eudoxe, les Pléiades se lèvent ; et changement de temps ». Les lignes conservées **sur le mécanisme** ne donnent que les événements astronomiques. | Bitsakis & Jones 2016 | haute |

## 3. Lire la FACE ARRIÈRE

| # | Fait | Source | Confiance |
|---|---|---|---|
| 3.1 | **Spirale du haut : le cycle de Méton.** Elle compte 5 tours et **235 cases**, soit 235 mois lunaires, soit **19 ans** (environ 6 940 jours). Chaque case porte un **nom de mois**. Le premier mois de chaque année porte aussi le signe « L » (« année ») suivi du **numéro de l'année, de 1 à 19**. Le bout de l'aiguille suit le sillon de la spirale grâce à un curseur, ce qui la garde sur le bon tour. Des traces ont été lues dans 49 cases, soit environ un tiers de la spirale. | Freeth et al. 2008 (+ SI) | haute |
| 3.2 | **Les 12 mois sont corinthiens** : Phoinikaios, Kraneios, Lanotropios, Machaneus, Dodekateus, Eukleios, Artemisios, Psydreus, Gameilios, Agrianios, Panamos, Apellaios. Ce calendrier est attesté à Corinthe, dans ses colonies, en Épire et, en partie, à Tauroménion (Sicile). Freeth et al. 2008 hésitent entre les colonies corinthiennes du Nord-Ouest et Syracuse. Pour Iversen 2017, c'est le **calendrier épirote** (peut-être venu d'Ambracie), dont l'année commence vers l'équinoxe d'automne. | Freeth et al. 2008 SI ; Iversen 2017 (*Hesperia* 86) | haute (noms) ; moyenne (quelle cité) |
| 3.3 | Des nombres inscrits signalent des « **jours exclus** ». Ils servaient à régler la longueur des mois (29 ou 30 jours), un système décrit par une source du Ier siècle av. J.-C. et jusque-là jugé invraisemblable. | Freeth et al. 2008 | haute |
| 3.4 | **Le cadran de Callippe (76 ans)** est un petit cadran à 4 secteurs dans la spirale du haut. Il est **RECONSTRUIT**, à partir d'une inscription « …76 ans… ». Le cycle de Callippe vaut 4 × 19 ans moins 1 jour, soit 27 759 jours (940 mois). | Freeth et al. 2008 SI | moyenne |
| 3.5 | **Le cadran des Jeux** a 4 secteurs et fait un tour en 4 ans. C'est le seul cadran qui tourne dans l'autre sens. Chaque année porte deux fêtes : **an 1 Isthmia + Olympia ; an 2 Nemea + Naa (Dodone) ; an 3 Isthmia + Pythia (Delphes) ; an 4 Nemea + Halieia (Rhodes, fête du Soleil)**. Les Naa ont été lues en 2008. La 4e fête (ΑΛΙΕΙΑ) a été lue plus tard ; le NAM écrit « probablement ». Le cadran indique **quels Jeux ont lieu cette année**, **pas leur jour exact**. | Freeth et al. 2008 SI ; Iversen 2017 ; Jones 2020 (table 4) ; NAM « The Greeks united fill the stadiums » | haute (Halieia : moyenne-haute) |
| 3.6 | **Spirale du bas : le Saros.** Elle compte 4 tours et **223 cases**, soit 223 mois lunaires (**environ 18 ans 11 jours et 8 heures**). Ce cycle d'éclipses babylonien remonte au VIIe siècle av. J.-C. Au bout de 223 mois, le Soleil, la Lune et les nœuds retrouvent presque la même configuration : les éclipses se répètent. | Freeth et al. 2008 ; Freeth 2019 (*Palgrave Commun.* 5:7) | haute |
| 3.7 | **Les glyphes.** Dans **51** des 223 cases, un signe annonce une éclipse possible. **Σ** (ΣΕΛΗΝΗ, la Lune) annonce une éclipse de Lune ; **Η** (ΗΛΙΟΣ, le Soleil) une éclipse de Soleil (quand les deux figurent, Σ vient d'abord). Suit la ligature **ΩΡ** (« heure ») avec une lettre-nombre de 1 à 12. **ΗΜ** (« de jour ») signale une éclipse de Lune qui tombe le jour, donc invisible ; **ΝΥ** (« de nuit ») une éclipse de Soleil de nuit. Tout en bas figure une **lettre d'index** (deux alphabets, le second surmonté d'une barre). Au total, on reconstruit **38 prédictions lunaires et 28 solaires**. | Freeth et al. 2008 SI ; Freeth 2014 (*PLoS ONE* 9:e103275) ; Freeth 2019 | haute (51/38/28 : moyenne-haute, schéma débattu par Anastasiou et al. 2016) |
| 3.8 | **Ce qui survit.** On connaissait **18 glyphes** en 2008. Les autres sont reconstruits par calcul. | Freeth et al. 2008 SI | moyenne-haute |
| 3.9 | Les lettres d'index renvoient à des **inscriptions autour du cadran**. Elles décrivent la **direction d'obscurcissement**, la **grandeur** et la **couleur** de l'éclipse. Price y voyait des vents ; Freeth 2014 y voit des directions d'obscurcissement. Selon Freeth, des inscriptions consacrées aux éclipses de Lune se trouvaient autour de la spirale du haut, mais elles sont perdues. | Freeth 2014 ; Freeth 2019 | moyenne-haute |
| 3.10 | **Le cadran Exeligmos** a 3 secteurs : **vide (0), Η (8), ΙϚ (16)**. Il indique **combien d'heures ajouter** à l'heure du glyphe. Un Saros dure environ 6 585 jours et 1/3, donc chaque éclipse revient environ **8 h plus tard**. Trois Saros forment un Exeligmos, soit environ 54 ans (19 756 jours). | Freeth et al. 2008 SI ; Freeth 2019 | haute |
| 3.11 | **Les heures.** Toutes les heures lues vont de 1 à 12. Le repère est incertain : ce seraient plutôt des heures égales, comptées depuis un lever ou un coucher du Soleil nominaux, à 6 h. | Freeth et al. 2008 SI §4.6 | moyenne |
| 3.12 | **Comment la liste des glyphes a été faite.** Ce n'est **pas une copie d'observations**. C'est un **calcul** mené avec des **méthodes arithmétiques babyloniennes**, et non avec la trigonométrie grecque (Carman & Evans 2014). Freeth 2014 propose deux modèles : l'un en « unités d'année d'éclipse », l'autre en « zigzag » tiré du Système B babylonien, avec une erreur d'environ 1,7 h. Les schémas babyloniens comptent 38 possibilités d'éclipse de Lune par Saros : 33 intervalles de 6 mois et 5 de 5 mois. | Carman & Evans 2014 (*AHES* 68) ; Freeth 2014 ; Freeth et al. 2008 SI | haute |
| 3.13 | **L'époque de départ.** La série d'éclipses a été calculée pour **205-187 av. J.-C.** La pleine lune du mois 1 tombe le **12 mai 205 av. J.-C.**, un résultat trouvé indépendamment par Carman & Evans 2014 et par Freeth 2014. Le calendrier (spirale du haut et cadran des Jeux) partirait 4 mois plus tard, à la nouvelle lune du **23 août 205 av. J.-C.** L'époque de départ **n'est pas la date de fabrication**. | Carman & Evans 2014 ; Freeth 2014 ; Iversen 2017 ; Jones 2020 | haute |
| 3.14 | **La précision.** La machine est ingénieuse mais imprécise : ses dents triangulaires sont limées à la main, avec du jeu. Freeth & Jones 2012 : elle « didn't really work very well » (« ne fonctionnait pas vraiment très bien »). Freeth 2014 : le schéma d'éclipses « n'était pas entièrement exact ». | Freeth & Jones 2012 ; Freeth 2014 | haute |

## 4. Prédire une éclipse comme un Grec ancien (pas à pas)

Exemple réel, tiré de Freeth 2014. L'utilisateur tourne la manivelle jusqu'au mois voulu. L'aiguille du Saros arrive dans la case 78. Le glyphe y annonce une **éclipse de Soleil à la 1re heure après l'aube**, avec la lettre d'index **T**. L'utilisateur cherche T dans la ligne 36 de l'inscription. Au-dessus, six lignes décrivent l'éclipse : directions, grandeur et couleur.

1. **Régler la machine sur aujourd'hui.** Placer l'anneau égyptien, puis tourner la manivelle jusqu'à ce que l'aiguille du Soleil montre la date du jour. En haut, l'aiguille de Méton doit montrer le mois lunaire courant.
2. **Avancer dans le temps.** Tourner la manivelle vers l'avant. L'aiguille du Saros (en bas) avance d'une case par mois lunaire, en suivant le sillon de la spirale.
3. **Guetter un glyphe.** On s'arrête dès que l'aiguille entre dans une case gravée.
4. **Lire le type.** Σ annonce une éclipse de Lune, à la pleine lune de ce mois. Η annonce une éclipse de Soleil, à la nouvelle lune.
5. **Lire l'heure.** Relever le nombre après ΩΡ. La mention ΗΜ (de jour) signifie qu'une éclipse de Lune aura lieu le jour : on ne la verra pas. ΝΥ (de nuit) signifie la même chose pour une éclipse de Soleil.
6. **Corriger l'heure.** Regarder le petit cadran Exeligmos et ajouter 0, 8 ou 16 heures.
7. **Lire les détails.** Chercher la lettre d'index dans les inscriptions autour du cadran : direction d'obscurcissement, grandeur, couleur.
8. **Dater l'éclipse.** La spirale de Méton donne le nom du mois et l'année du cycle. Le cadran des Jeux situe l'année (« l'année des Olympia », par exemple). À l'avant, les aiguilles du Soleil et de la Lune sont superposées (nouvelle lune) ou opposées (pleine lune).
9. **Garder en tête les limites.** Le glyphe annonce une **possibilité** d'éclipse. Il ne dit pas **où** une éclipse de Soleil sera visible. L'heure peut être fausse de quelques heures, et l'erreur grandit à mesure qu'on s'éloigne de l'époque de départ.

## 5. Navigation : ce que la machine n'était pas, et le vrai lien avec la mer

| # | Fait | Source | Confiance |
|---|---|---|---|
| 5.1 | **Ce n'était pas un instrument de navigation.** Rien dans la machine ne sert à se situer en mer : aucun organe de visée, aucune échelle de hauteur d'astre, ni latitude ni longitude. Ses cadrans donnent des calendriers, des positions célestes, des éclipses et des Jeux. Les spécialistes la décrivent comme un calculateur astronomique qui figure le **cosmos** (Freeth et al. 2021), ou comme un **appareil d'enseignement et de démonstration** (Jones 2017). M. T. Wright y voit un planétaire, « sans rôle dans la navigation ». | Freeth et al. 2021 ; Jones 2017 (compte rendu BMCR 2018.05.16) ; Wright, cité par Wyse 2022 | haute |
| 5.2 | **Hypothèses minoritaires.** Rediadis y voyait un astrolabe (début du XXe siècle), mais aucune trace physique ne le confirme. Wyse 2022 (revue *Coordinates*) propose la méthode des « distances lunaires », une technique des marins des XVIIIe-XIXe siècles : l'hypothèse reste isolée et non démontrée. Une page grand public du NAM mentionne un usage « probablement » lié à « l'astrologie et la navigation », sans preuve publiée. | Wyse 2022 ; NAM *archaeologist* | moyenne |
| 5.3 | **Le vrai lien avec la mer : le calendrier du ciel.** Le parapegme de la machine suit justement les astres des marins et des paysans : Pléiades, Hyades, Orion, Sirius, Arcturus. Ces astres disaient **quand** on pouvait prendre la mer. | Bitsakis & Jones 2016 | haute |
| 5.4 | **Hésiode**, *Les Travaux et les Jours*, v. 383-384 (trad. Leconte de Lisle, 1869) : « Au lever des Plèiades, filles d'Atlas, commence la moisson, et le labourage à leur coucher. » | Hésiode, trad. Leconte de Lisle (Wikisource) | haute |
| 5.5 | **Hésiode**, v. 618-622 : « Si le désir de la navigation dangereuse te saisit, crains le temps où les Plèiades, fuyant la force terrible d'Oriôn, tombent dans la noire mer. Alors, certes, les souffles des vents nombreux se déchaînent. Ne laisse pas plus longtemps tes nefs sur la noire mer… » (Le coucher des Pléiades a lieu vers fin octobre - début novembre.) Au v. 663 : « Cinquante jours après la conversion de Hèlios [le solstice d'été], à la fin de la laborieuse saison d'été, c'est le temps de la navigation pour les mortels. » | Hésiode, trad. Leconte de Lisle ; dates : Evelyn-White 1914 | haute |
| 5.6 | **Végèce**, *Epitoma rei militaris* IV, 39 (fin IVe - début Ve siècle apr. J.-C., donc bien après la machine). La navigation est jugée **sûre du 27 mai au 14 septembre**, soit « après le lever des Pléiades » et jusqu'au « lever d'Arcturus ». Elle est **incertaine** jusqu'au 11 novembre. « Le coucher hivernal des Pléiades » amène les tempêtes. **Du 11 novembre au 10 mars, les mers sont fermées** (*maria clauduntur*). | Végèce IV, 39 (texte latin, The Latin Library) | haute |
| 5.7 | Végèce ouvre la saison par « **Pachone decurso**, c'est-à-dire après le lever des Pléiades ». **Pachon** est un mois égyptien, et son nom **ΠΑΧΩΝ** subsiste sur l'anneau du calendrier égyptien de la machine. | Végèce IV, 39 ; Bitsakis & Jones 2016 | haute |
| 5.8 | **Naviguer aux étoiles.** Selon Aratos (*Phénomènes*, v. 37-44), les Grecs se dirigent sur la **Grande Ourse** (Hélikè) et les Phéniciens sur la **Petite Ourse** (Kynosoura), « meilleure pour les marins ». Dans l'*Odyssée* (V, 270-277), Ulysse observe les Pléiades, le Bouvier et l'Ourse : Calypso lui a ordonné de naviguer en gardant l'Ourse **à sa gauche**. | Aratos, trad. Mair (theoi.com) ; Homère, trad. Leconte de Lisle | haute |
| 5.9 | **Soleil, étoiles, sonde et saison.** Le voyage de Paul (Actes 27, Ier siècle apr. J.-C.) en donne un exemple concret. La navigation devient « dangereuse » après « le jeûne » (automne). Pendant la tempête, « ni soleil ni étoiles n'apparurent pendant plusieurs jours ». Près de la côte, les marins **sondent** : 20 brasses, puis 15. | Actes 27, 9 ; 27, 20 ; 27, 28 | haute |
| 5.10 | **Les autres repères.** Les marins antiques suivaient surtout la **côte** et ses amers. Ils lisaient le **vent**, le **Soleil** le jour et les **étoiles** la nuit. La **boussole** n'apparaît en Méditerranée qu'au Moyen Âge (fin du XIIe siècle). | Histoire générale des techniques (Alexandre Neckam, v. 1190) | moyenne |

**Phrase clé pour la voix off** : « La machine ne disait pas aux marins **où** aller. Son calendrier du ciel disait **quand** la mer était ouverte. »

## 6. Éclipses réelles 2026-2028 (catalogues NASA, F. Espenak)

La NASA donne les heures en temps dynamique (TD). Nous les avons converties en temps universel (UT = TD − ΔT), avec le ΔT prédit par la NASA (75 à 77 s). Les heures UT sont arrondies à la minute.

| Date | Heure UT (TD NASA) | Type | Saros | Où voir |
|---|---|---|---|---|
| 2026-02-17 | 12:12 (12:13:06) | Soleil, **annulaire** | 121 | Partielle : sud de l'Argentine et du Chili, Afrique australe, Antarctique. Annulaire : Antarctique |
| 2026-03-03 | 11:34 (11:34:52) | Lune, **totale** (1,151) | 133 | Est de l'Asie, Australie, Pacifique, Amériques |
| 2026-08-12 | 17:46 (17:47:06) | Soleil, **totale** (2 min 18 s au maximum) | 126 | Totale : Arctique, Groenland, Islande, **Espagne**. Partielle : nord de l'Amérique du Nord, ouest de l'Afrique, Europe (dont la France) |
| 2026-08-28 | 04:13 (04:14:04) | Lune, **partielle** (0,930) | 138 | Est du Pacifique, Amériques, Europe, Afrique |
| 2027-02-06 | 16:00 (16:00:48) | Soleil, **annulaire** | 131 | Amérique du Sud, Antarctique, ouest et sud de l'Afrique. Annulaire : Chili, Argentine, Atlantique |
| 2027-02-20 | 23:13 (23:14:06) | Lune, **pénombrale** | 143 | Amériques, Europe, Afrique, Asie |
| 2027-07-18 | 16:03 (16:04:09) | Lune, **pénombrale** (à peine : grandeur 0,0014) | 110 | Est de l'Afrique, Asie, Australie, Pacifique |
| 2027-08-02 | 10:07 (10:07:50) | Soleil, **totale** (6 min 23 s) | 136 | Totale : **Maroc, Espagne (sud)**, Algérie, Libye, **Égypte**, Arabie saoudite, Yémen, Somalie. Partielle : Afrique, Europe, Moyen-Orient, ouest et sud de l'Asie |
| 2027-08-17 | 07:14 (07:14:59) | Lune, **pénombrale** | 148 | Pacifique, Amériques |
| 2028-01-12 | 04:13 (04:14:13) | Lune, **partielle** (0,066) | 115 | Amériques, Europe, Afrique |
| 2028-01-26 | 15:08 (15:08:59) | Soleil, **annulaire** (10 min 27 s) | 141 | Annulaire : Équateur, Pérou, Brésil, Suriname, **Espagne, Portugal**. Partielle : est de l'Amérique du Nord, Amérique centrale et du Sud, ouest de l'Europe, nord-ouest de l'Afrique |
| 2028-07-06 | 18:20 (18:20:57) | Lune, **partielle** (0,389) | 120 | Europe, Afrique, Asie, Australie |
| 2028-07-22 | 02:55 (02:56:40) | Soleil, **totale** (5 min 10 s) | 146 | Totale : Australie, Nouvelle-Zélande. Partielle : Asie du Sud-Est, Indonésie, Australie, Nouvelle-Zélande |
| 2028-12-31 | 16:52 (16:53:15) | Lune, **totale** (1,246) | 125 | Europe, Afrique, Asie, Australie, Pacifique |

Sources : `eclipse.gsfc.nasa.gov/SEdecade/SEdecade2021.html`, `LEdecade/LEdecade2021.html`, `SEcat5/SE2001-2100.html`, `LEcat5/LE2001-2100.html`.

**Le Saros en action (données NASA)**
- L'éclipse totale du **12 août 2026** (Saros 126) reprend celle du **1er août 2008** (10:22 TD), 18 ans et 11 jours plus tard, environ 7 h 25 min plus tard dans la journée.
- L'éclipse totale du **2 août 2027** (Saros 136) reprend celle du **22 juillet 2009** (la plus longue totalité du XXIe siècle, 6 min 39 s). Elle reviendra le **12 août 2045**.

**Pour comparer avec notre machine**
- L'époque de notre modèle n'est pas calibrée. Il faut d'abord caler la manivelle sur une pleine lune connue, puis comparer mois par mois.
- La machine donne le mois et une heure approximative, mais pas la zone de visibilité.
- Les schémas antiques ne distinguent pas les éclipses pénombrales. Freeth et al. 2008 notent que les concordances dépendent de l'inclusion de ces éclipses faibles.

## 7. Mythes à éviter
Voir la liste plus bas (identique à la sortie structurée).

1. « C'était un instrument de navigation. » **Faux.** Aucun organe de visée ni échelle de position. C'est un calculateur et un modèle du cosmos. Le lien avec la mer passe seulement par le calendrier des étoiles.
2. « C'est le premier ordinateur. » **À nuancer.** Le mot vient de Price (1959, « An Ancient Greek Computer »). C'est un **calculateur analogique à engrenages, actionné à la main** : pas programmable, sans mémoire ni électricité. On peut dire « le plus ancien calculateur astronomique à engrenages connu ».
3. « Archimède l'a construit. » **Non prouvé.** Cicéron parle de « sphères » d'Archimède et de Posidonios. L'époque de départ, 205 av. J.-C., est proche de la mort d'Archimède (212 av. J.-C.), mais l'époque n'est pas la date de fabrication, et l'objet a pu être fait jusque vers 60 av. J.-C.
4. « On sait qu'il a été fabriqué à Rhodes / à Corinthe. » **Hypothèses.** Rhodes (Halieia, Posidonios) est plausible ; le calendrier est corinthien et pointe vers un usage en Épire.
5. « Il a été découvert en 1901. » **À préciser.** L'épave est trouvée en 1900, les fragments sont remontés en 1900-1901, et le mécanisme n'est remarqué qu'en 1902.
6. « Il donnait la date exacte des Jeux olympiques. » **Non.** Il indiquait l'**année** du cycle de 4 ans et les Jeux de cette année (Olympia, Isthmia, Nemea, Pythia, Naa, Halieia), pas le jour.
7. « Il prédisait exactement où et quand on verrait une éclipse. » **Non.** Il annonçait des **possibilités** d'éclipse, avec le mois et une heure approximative (plus ou moins quelques heures). La visibilité locale d'une éclipse de Soleil était hors de sa portée.
8. « On a retrouvé les engrenages des planètes. » **Non.** L'affichage des planètes est attesté par les inscriptions, mais ses engrenages sont **reconstruits** (hypothétiques). L'aiguille du Dragon est une hypothèse sans preuve physique.
9. « C'était une mécanique d'une précision parfaite. » **Non.** Les dents triangulaires limées à la main et le jeu créaient des erreurs.
10. « Un objet trop avancé pour son époque (extraterrestre, faux moderne). » **Faux.** Il s'inscrit dans la science hellénistique : Hipparque, les cycles babyloniens, les sphères citées par Cicéron. Son authenticité est établie (Jones 2020, annexe).
11. « Les couleurs ou les pierres des planètes sont connues. » **Non.** Seule la « petite sphère dorée » du Soleil est attestée ; le reste est conjectural ou moderne.
12. « Les glyphes montrés dans la vidéo sont ceux de l'original. » **Non**, sauf mention contraire. Environ 18 glyphes originaux ont été lus ; les nôtres sont **calculés par notre modèle**.
13. « Le calendrier avait certainement 365 trous. » **Débattu** : 365, ou 354-355 (une année lunaire) selon les études récentes.
14. « Il marchait tout seul, comme une horloge. » **Non.** On tournait une manivelle à la main pour avancer ou reculer dans le temps. Aucun moteur ni ressort n'est attesté.

---

## 8. Guide de lecture pour un spectateur d'aujourd'hui

(Identique à `reading_guide_fr` de la sortie structurée.)

**Avant de commencer.** On ne « met pas en marche » la machine : on **tourne une manivelle** sur le côté. Toutes les aiguilles avancent ensemble. Tourner vers l'avant fait avancer le temps ; tourner en arrière le fait reculer. Dans notre modèle, environ 4,6 tours de manivelle correspondent à 1 an (la grande roue fait 1 tour par an).

**FACE AVANT : le ciel d'aujourd'hui**
1. **La date.** Suivez l'aiguille du Soleil (la sphère dorée). Sur l'**anneau extérieur**, elle montre le jour de l'année égyptienne de 365 jours (12 mois de 30 jours plus 5 jours). Sur l'**anneau intérieur**, elle montre où se trouve le Soleil dans le zodiaque (12 signes de 30°). Autrefois, on tournait d'abord l'anneau égyptien, fixé par une cheville, pour rattraper le quart de jour perdu chaque année.
2. **La saison.** Regardez la petite lettre gravée sous l'aiguille du Soleil, puis cherchez la même lettre sur les plaques du haut et du bas (le parapegme). Vous lisez par exemple « Ξ — La Pléiade se lève le matin » : pour Hésiode, c'est le signal des moissons, vers le début de mai.
3. **La Lune.** L'aiguille de la Lune montre sa place dans le zodiaque. Elle accélère et ralentit, comme la vraie Lune, grâce à la « goupille et fente » d'Hipparque.
4. **La phase de la Lune.** La petite boule mi-noire mi-blanche tourne sur elle-même. Noire, c'est la nouvelle lune (Lune et Soleil alignés). Blanche, c'est la pleine lune (Lune à l'opposé du Soleil). Moitié-moitié, c'est un quartier. Plus l'angle entre les aiguilles de la Lune et du Soleil est grand, plus la Lune est « vieille » dans son mois.
5. **Les planètes (reconstruction).** Chaque petite sphère sur son anneau (du centre vers le bord : Mercure, Vénus, Soleil, Mars, Jupiter, Saturne) se lit sur le zodiaque. Si une sphère s'arrête puis **recule**, c'est la **rétrogradation**. Mercure et Vénus ne s'éloignent jamais beaucoup du Soleil. (Les couleurs sont modernes et les engrenages hypothétiques.)
6. **L'aiguille du Dragon (hypothétique).** Elle montre les nœuds de la Lune. Si la nouvelle lune ou la pleine lune tombe près de cette aiguille, une éclipse est possible.

**FACE ARRIÈRE : le calendrier et les éclipses**
7. **Le mois et l'année (spirale du haut, 235 cases, 19 ans).** Le bout de l'aiguille glisse dans le sillon de la spirale. La case désignée donne le **nom du mois** (calendrier corinthien, Phoinikaios par exemple) et l'**année du cycle** (1 à 19).
8. **Les Jeux (petit cadran dans la spirale du haut).** L'aiguille montre l'année 1 à 4 et les fêtes de cette année : an 1 Isthmia et **Olympia** ; an 2 Nemea et Naa ; an 3 Isthmia et Pythia ; an 4 Nemea et Halieia. On apprend « les Jeux olympiques ont lieu cette année », pas le jour exact.
9. **Les 76 ans (cadran de Callippe, reconstruit).** Il indique dans lequel des quatre cycles de 19 ans on se trouve.
10. **Les éclipses (spirale du bas, 223 cases).** Une case vide signifie pas d'éclipse ce mois-ci. Une case gravée annonce une éclipse **possible** : **Σ** pour la Lune (à la pleine lune), **Η** pour le Soleil (à la nouvelle lune), puis **ΩΡ** et un chiffre pour l'heure. **ΗΜ** veut dire « de jour » : une éclipse de Lune invisible. **ΝΥ** veut dire « de nuit » : une éclipse de Soleil invisible.
11. **La correction d'heure (petit cadran Exeligmos).** Ajoutez **0, 8 ou 16 heures** selon le secteur, car chaque Saros décale l'heure d'environ 8 h.
12. **Les détails.** La lettre d'index du glyphe renvoie à un texte gravé autour du cadran, qui décrit la direction d'obscurcissement, la grandeur et la couleur.

**Pour résumer.** Tournez jusqu'à la date voulue et lisez dans l'ordre : Soleil (date et saison), Lune (position et phase), planètes, puis, au dos, le mois, les Jeux et, s'il y a un glyphe, l'éclipse et son heure corrigée.

---

## 9. Notes pour l'équipe : écarts entre notre modèle et les sources

Ces points sont à corriger ou à signaler à l'écran.

- **Cadran des Jeux.** La spec `dials.back.subsidiary[olympiad].labels` porte un nom par secteur (ΙΣΘΜΙΑ, ΟΛΥΜΠΙΑ, ΝΕΜΕΑ, ΠΥΘΙΑ). L'original en porte deux par année : 1 ΙΣΘΜΙΑ + ΟΛΥΜΠΙΑ ; 2 ΝΕΜΕΑ + ΝΑΑ ; 3 ΙΣΘΜΙΑ + ΠΥΘΙΑ ; 4 ΝΕΜΕΑ + ΑΛΙΕΙΑ. Il faut le dire en voix off ou corriger les étiquettes.
- **Orientation du zodiaque.** D'après Bitsakis & Jones 2016, le 0° du Bélier (équinoxe de printemps) était **en haut**. Notre modèle le place à 3 h (+x).
- **Orthographe d'un mois égyptien.** Le mois ΕΠΙΦΙ de la spec s'écrit **ΕΠΕΙΦ** sur l'original (Ἐπείφ, Bitsakis & Jones 2016).
- **Exeligmos.** Le chiffre 16 s'écrit **ΙϚ** sur l'original (stigma). La spec écrit ΙΣΤ faute de glyphe dans la police Blender : à signaler si c'est lisible à l'écran.
- **Nombre de trous du calendrier.** La valeur de la spec (354) suit Budiselić et al. 2020 et Woan & Bayley 2024 ; elle est débattue face à 365.
- **Époque non calibrée.** Tous nos glyphes sont calculés par notre modèle. Pour une « vraie » époque, il faudrait caler le mois 1 du Saros sur la pleine lune du 12 mai 205 av. J.-C. (Carman & Evans 2014 ; Freeth 2014).
- **Boule des phases.** L'original est décrit « moitié noire, moitié blanche ». Notre boule argent et sombre est acceptable.

## 10. Sources

- Freeth T. et al. (2006). « Decoding the ancient Greek astronomical calculator known as the Antikythera Mechanism ». *Nature* 444:587-591. doi:10.1038/nature05357. https://www.nature.com/articles/nature05357
- Freeth T., Jones A., Steele J. M., Bitsakis Y. (2008). « Calendars with Olympiad display and eclipse prediction on the Antikythera Mechanism ». *Nature* 454:614-617. doi:10.1038/nature07130. SI : https://archive.nyu.edu/bitstream/2451/60882/2/Freeth_Jones_Steele_Bitsakis_2008_supplementary.pdf
- Freeth T., Jones A. (2012). « The Cosmos in the Antikythera Mechanism ». *ISAW Papers* 4. http://dlib.nyu.edu/awdl/isaw/isaw-papers/4/
- Freeth T. (2014). « Eclipse Prediction on the Ancient Greek Astronomical Calculating Machine Known as the Antikythera Mechanism ». *PLoS ONE* 9(7):e103275. https://journals.plos.org/plosone/article?id=10.1371/journal.pone.0103275
- Carman C. C., Evans J. (2014). « On the epoch of the Antikythera mechanism and its eclipse predictor ». *Archive for History of Exact Sciences* 68:693-774. https://philpapers.org/rec/EVAOTE-2 (résumé : https://phys.org/news/2014-11-antikythera-mechanism-clues-ancient-greek.html)
- Bitsakis Y., Jones A. (2016). « The Front Dial and Parapegma Inscriptions ». *Almagest* 7.1 (IAM 3). https://archive.nyu.edu/jspui/bitstream/2451/71597/6/IAM%203%20bitsakis-jones-2016-the-front-dial-and-parapegma-inscriptions.pdf
- Anastasiou M. et al. (2016). « The Back Dial and Back Plate Inscriptions ». *Almagest* 7.1:138-215.
- Iversen P. A. (2017). « The Calendar on the Antikythera Mechanism and the Corinthian Family of Calendars ». *Hesperia* 86.1:129-203. https://www.jstor.org/stable/10.2972/hesperia.86.1.0129
- Jones A. (2017). *A Portable Cosmos*. Oxford University Press. Compte rendu BMCR 2018.05.16 : https://bmcr.brynmawr.edu/2018/2018.05.16/
- Freeth T. (2019). « Revising the eclipse prediction scheme in the Antikythera mechanism ». *Palgrave Communications* 5:7. doi:10.1057/s41599-018-0210-9
- Jones A. (2020). « The Epoch Dates of the Antikythera Mechanism ». *ISAW Papers* 17. http://dlib.nyu.edu/awdl/isaw/isaw-papers/17/
- Freeth T. et al. (2021). « A Model of the Cosmos in the ancient Greek Antikythera Mechanism ». *Scientific Reports* 11:5821. https://www.nature.com/articles/s41598-021-84310-w
- Woan G., Bayley J. (2024). « An improved calendar ring hole-count for the Antikythera mechanism ». arXiv:2403.00040
- Musée national archéologique d'Athènes : https://www.namuseum.gr/en/monthly_artefact/the-greeks-united-fill-the-stadiums/ ; https://antikythera-mechanism.namuseum.gr/en/archaeologist/ ; https://www.namuseum.gr/en/temporary_exhibition/to-nayagio-ton-antikythiron-to-ploio-oi-thisayroi-o-michanismos/
- WHOI, *Antikythera shipwreck* : https://www.whoi.edu/ocean-learning-hub/ocean-topics/ocean-human-lives/underwater-archaeology/antikythera-shipwreck/
- Hésiode, *Les Travaux et les Jours*, trad. Leconte de Lisle (Wikisource) ; trad. angl. Evelyn-White 1914 : https://www.theoi.com/Text/HesiodWorksDays.html
- Végèce, *Epitoma rei militaris* IV, 39 : https://www.thelatinlibrary.com/vegetius4.html
- Homère, *Odyssée* V, trad. Leconte de Lisle (Wikisource) ; Aratos, *Phénomènes* : https://www.theoi.com/Text/AratusPhaenomena.html
- Actes des Apôtres 27 (KJV, Project Gutenberg n° 10)
- NASA/GSFC (F. Espenak), catalogues d'éclipses : https://eclipse.gsfc.nasa.gov/SEdecade/SEdecade2021.html ; https://eclipse.gsfc.nasa.gov/LEdecade/LEdecade2021.html ; https://eclipse.gsfc.nasa.gov/SEcat5/SE2001-2100.html ; https://eclipse.gsfc.nasa.gov/LEcat5/LE2001-2100.html
- Wyse J. E. (2022). *Coordinates* (hypothèse minoritaire sur la navigation) : https://mycoordinates.org/the-antikythera-mechanism-discerning-its-role-in-ancient-navigation/

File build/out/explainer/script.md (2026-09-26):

# Le ciel dans une boîte : comment lire la machine d'Anticythère

Script de la voix off et découpage du film explicatif.
Version du 25 septembre 2026 (relue et corrigée). Texte parlé seul : `narration.txt` (un paragraphe par chapitre, séparés par `---`).

## Fiche technique

| | |
|---|---|
| Durée visée | environ 2 min 45 s (165 s, carton final compris) |
| Texte parlé | 385 mots (390 en lisant les années en toutes lettres). Débit posé : 2,3 à 2,4 mots par seconde selon le chapitre, jamais plus, pour garder de courtes pauses |
| Voix | française, calme, ton documentaire, vouvoiement |
| Look | atelier en lumière du jour (`tools/staging_atelier.py`, collection AM_ATELIER). Bronze clair, patine faible (0,15) sauf au chapitre 1. Graphismes crème et encre, accents or et bronze, lettres grecques en or |
| Manivelle | `AM_Controller["crank"]` en années. Le temps avance globalement du début à la fin du film, de 0 à 9,6 ans (sauf les éclairs du plan 1.2, le retour en arrière du plan 2.2 et la reprise du plan 4.3) |
| Compteur | Coin haut gauche, à partir du chapitre 2 : « Temps écoulé : X ans Y j » (Y = partie décimale × 365,2422). Il indique un temps relatif, jamais une date historique, parce que l'époque du modèle n'est pas calibrée |
| Règles | Chaque fait vient de la fiche vérifiée (`faits.md`). Planètes, Soleil vrai et aiguille du Dragon sont marqués « hypothèse ». Les signes d'éclipse sont marqués « calculés par notre modèle ». La machine n'est pas présentée comme un instrument de navigation |

## Ligne de temps de la manivelle

Les instants ci-dessous ont été recontrôlés le 25 septembre avec `tools/explainer/engine.py` (machine non calée, identique aux drivers de `am.blend` à 6,4e-7 rad près, voir `validate_blend.json`). Les signes d'éclipse viennent de `glyphs.json` (`modele_epoque_t0`, règle `limits`), la même table que la page web. Il faudra quand même recontrôler dans Blender avant le rendu, avec la méthode de `tools/crosscheck_blend.py`.

| Chap. | Manivelle (ans) | Ce qui se passe dans notre modèle |
|---|---|---|
| 1 | 0 (explode 1 → 0, patina 1 → 0,15). Éclairs du plan 1.2 à 9,014 · 0,99 · 2,31 · 5,95 | la machine se remonte |
| 2 | 0 → 0,6 → 0,7 → 0,3 → 0,972 | nouvelle lune à 0,972 : aiguilles de la Lune et du Soleil superposées, boule noire |
| 3 | 0,972 → 1,009 | pleine lune à 1,009 : Lune vers 182° (2° dans ΧΗΛΑΙ), sphère dorée vers 5° et aiguille de date vers 3° (dans ΚΡΙΟΣ) |
| 4 | 1,009 → 2,10 → 2,52 | Mars s'arrête vers 2,213, recule jusqu'à 2,413 environ, puis repart (opposition vers 2,31) |
| 5 | 2,52 → 5,95 | Jeux (étiquettes actuelles du modèle) : ΟΛΥΜΠΙΑ (an 1) jusqu'à 2,911, puis ΙΣΘΜΙΑ (an 2, étiquette fausse, voir note 2), ΠΥΘΙΑ (an 3, dès 3,911), ΝΕΜΕΑ (an 4, dès 4,911), et de nouveau ΟΛΥΜΠΙΑ dès 5,911 |
| 6 | 5,95 → 8,66 (rapide) → 8,98 (lent) → 9,014 | l'aiguille du Saros quitte la case 107 (signe Η) à 8,651. Les cases 108 à 111 sont sans signe. Elle entre dans la case 112 à 8,975 (signe calculé « Σ Η »). Nouvelle lune à 8,976 (Lune à 15,1° du nœud), pleine lune à 9,014 (Lune à 0,5° de l'aiguille du Dragon). L'Exeligmos est dans le secteur vide (+0 h) |
| 7 | 9,014 → 9,13 → 9,60 | le Soleil passe vers 47° (17° dans ΤΑΥΡΟΣ), puis vers 216° (ΣΚΟΡΠΙΟΣ) |

---

## 1. Le ciel dans une boîte (environ 24 s)

> Il y a plus de deux mille ans, quelqu'un a enfermé le ciel dans une boîte : éclipses, phases de la Lune, planètes, et même les Jeux olympiques. En 1900, des pêcheurs d'éponges découvrent l'épave d'Anticythère. En 1902, sur un bloc de bronze rongé, apparaît une roue dentée. Apprenons à lire cette machine.

| Plan | Durée | Cadrage | Action | Textes à l'écran | Schéma 2D |
|---|---|---|---|---|---|
| 1.1 | 0-6,5 s | Atelier inondé de lumière, boîtier en bois fermé sur l'établi (mode `case`), lent travelling avant | Rien ne bouge (crank 0). Il faut accrocher le regard dans les 5 premières secondes : un rai de soleil glisse sur le boîtier | (aucun) | (aucun) |
| 1.2 | 6,5-10,5 s | Quatre plans serrés d'une seconde sur la reconstruction (patine 0,15), calés sur l'énumération | « éclipses » : face avant à 9,014 (Soleil, Lune et aiguille du Dragon alignés, sans signe d'éclipse) ; « phases » : boule des phases à 0,99 (moitié claire) ; « planètes » : sphères et étiquettes à 2,31 ; « Jeux » : secteur ΟΛΥΜΠΙΑ à 5,95 | (aucun) | (aucun) |
| 1.3 | 10,5-14,5 s | Carte animée, mer agitée | Un point « épave » pulse près d'Anticythère | « Printemps 1900 » · « Pêcheurs d'éponges de Symi » · « 40–50 m de fond » | Carte stylisée : Péloponnèse, Cythère, Anticythère, Crète |
| 1.4 | 14,5-24 s | Gros plan en lumière rasante sur une roue corrodée, puis recul jusqu'au trois-quarts avant (`front34`) | patina 1, explode 1 (pièces dispersées), lente rotation de la caméra. Sur « Apprenons… » (vers 20,5 s) : explode 1 → 0 et patina 1 → 0,15, les pièces se remontent et le bronze s'éclaircit | « 1902 : une roue dentée » · « 82 fragments · ≈ 1/3 » · « 30 roues dentées conservées », puis « Notre reconstruction · 69 roues » | (aucun) |

## 2. La manivelle, c'est le temps (environ 14 s)

> Voici notre reconstruction. Sur le côté, une manivelle. Tournez-la : toutes les aiguilles avancent ensemble. En avant, le temps passe ; en arrière, il remonte. Un peu plus de quatre tours et demi : une année.

| Plan | Durée | Cadrage | Action | Textes à l'écran | Schéma 2D |
|---|---|---|---|---|---|
| 2.1 | 0-6,5 s | Gros plan sur la manivelle, côté droit (arbre a) | crank 0 → 0,6. Le compteur apparaît | « La manivelle = le temps » · compteur « Temps écoulé » | (aucun) |
| 2.2 | 6,5-10 s | Trois-quarts avant, toutes les aiguilles dans le champ | Sur « En avant » : crank 0,6 → 0,7. Sur « en arrière » : 0,7 → 0,3, tout recule et le compteur redescend | « En arrière : le passé » | (aucun) |
| 2.3 | 10-14 s | Face avant, grande roue b1 surlignée derrière le cadran (léger fantôme) | crank 0,3 → 0,972, en accélérant | « ≈ 4,6 tours = 1 an » · « Grande roue : 1 tour/an » | (aucun) |

## 3. Lire la face avant (environ 24 s)

> Devant, deux anneaux : le calendrier égyptien de trois cent soixante-cinq jours, et le zodiaque. La sphère dorée, c'est le Soleil : il donne la date et son signe. La Lune fait le tour en un mois, à vitesse variable, comme la vraie. Sa petite boule montre la phase. Aiguilles superposées : noire, nouvelle lune. Opposées : blanche… pleine lune.

| Plan | Durée | Cadrage | Action | Textes à l'écran | Schéma 2D |
|---|---|---|---|---|---|
| 3.1 | 0-6 s | Face avant rapprochée (`CAM_front_close`) | crank fixé à 0,972. Un reflet balaie l'anneau extérieur, puis l'anneau intérieur | « Calendrier égyptien · 365 j » · « Zodiaque · 12 signes » | (aucun) |
| 3.2 | 6-11 s | Même cadrage | La sphère dorée et l'aiguille de date s'allument. Deux traits fins partent vers l'anneau extérieur (date) et l'anneau intérieur (signe) | « Soleil : date + signe » · en petit : « Sphère dorée : citée par l'inscription · son engrenage : hypothèse » | (aucun) |
| 3.3 | 11-16,5 s | Aiguille de la Lune | L'aiguille est surlignée, crank toujours à 0,972 (superposée au Soleil) | « Lune : 1 tour/mois » · « Vitesse variable (Hipparque) » | Option : petite courbe de vitesse de la Lune sur un mois |
| 3.4 | 16,5-24 s | Très gros plan sur la boule des phases, en incrustation dans la face avant | La boule est noire au départ. Sur « Opposées », crank 0,972 → 1,009, puis tenue 1 s sur la boule blanche | « Superposées : nouvelle lune » · « Opposées : pleine lune » · « Lune dans ΧΗΛΑΙ (Balance) » | Petit schéma vu de dessus (Soleil, Terre, Lune) : la Lune passe de « entre les deux » à « opposée » |

## 4. Les planètes, une hypothèse (environ 17 s)

> Autour du centre, cinq petites sphères : les planètes, lues sur le zodiaque. Leurs engrenages ont presque tous disparu : c'est une reconstruction, une hypothèse. Regardez Mars : sa sphère s'arrête… puis recule, comme dans le ciel quand la Terre dépasse Mars.

| Plan | Durée | Cadrage | Action | Textes à l'écran | Schéma 2D |
|---|---|---|---|---|---|
| 4.1 | 0-9 s | Face avant rapprochée, étiquettes des planètes visibles (AM_LABELS) | crank 1,009 → 2,10 à vitesse moyenne | « Planètes : lire sur le zodiaque » · « Hypothèse · Freeth et al. 2021 » · « Couleurs modernes » | (aucun) |
| 4.2 | 9-13 s | Cadrage serré sur la sphère rouge de Mars et son anneau | crank 2,10 → 2,52 lentement. Arrêt vers 2,213, recul jusqu'à 2,413 environ. Une traînée lumineuse sur l'anneau montre l'aller-retour | « Station » · « Rétrogradation » · « “stêrigmos” dans l'inscription » | (aucun) |
| 4.3 | 13-17 s | Écran partagé : la machine à gauche, le schéma à droite | Reprise de la même plage de manivelle (compteur masqué pendant la reprise), synchronisée avec le schéma | « Vue de la Terre » · « La Terre dépasse Mars » | Soleil au centre, orbites de la Terre et de Mars. Les lignes de visée Terre → Mars se projettent sur une bande d'étoiles et y dessinent une boucle |

## 5. Le dos : les mois et les Jeux (environ 18 s)

> Retournons la machine. En haut, une spirale de deux cent trente-cinq mois : dix-neuf ans. Chaque case, un mois, avec son nom. Dedans, un petit cadran fait un tour en quatre ans. Tournons… Olympia ! Cette année, les Jeux olympiques. L'année, pas le jour.

| Plan | Durée | Cadrage | Action | Textes à l'écran | Schéma 2D |
|---|---|---|---|---|---|
| 5.1 | 0-2,5 s | Orbite de 180° autour de la machine, jusqu'à `CAM_back_close` | crank 2,52 → 2,6 | (aucun) | (aucun) |
| 5.2 | 2,5-9,5 s | Spirale du haut (Méton) | crank 2,6 → 3,0. Le curseur est surligné dans le sillon | « 235 mois = 19 ans » · « 1 case = 1 mois » · « Mois corinthiens » | Case agrandie, illustrative, d'après Freeth et al. 2008 : « Phoinikaios… an 1 » |
| 5.3 | 9,5-18 s | Petit cadran des Jeux, en gros plan | crank 3,0 → 5,95, rapide puis ralenti. L'aiguille arrive sur ΟΛΥΜΠΙΑ vers 5,911 et le secteur s'illumine. Les étiquettes du cadran sont remplacées par les paires historiques dans la copie de travail (note 2), sinon le secteur de l'an 2 contredit le bandeau | « 1 tour = 4 ans » · « Olympia : année des Jeux » · « L'année, pas le jour » | Bandeau des 4 années d'origine (Freeth et al. 2008, Iversen 2017) : « An 1 : Isthmia, Olympia » · « An 2 : Nemea, Naa » · « An 3 : Isthmia, Pythia » · « An 4 : Nemea, Halieia » |

## 6. Prédire une éclipse (environ 30 s)

> En bas, le Saros : deux cent vingt-trois mois, puis les éclipses reviennent. La plupart des cases sont vides. Tournons… Une case gravée ! Sigma : éclipse de Lune. Êta : de Soleil. Puis l'heure ; ce cadran y ajoute zéro, huit ou seize heures. Devant, la pleine lune tombe sur l'aiguille du Dragon, hypothétique elle aussi : une éclipse est possible. Attention : ces signes sont calculés par notre modèle. Et la machine ne disait pas où l'observer.

| Plan | Durée | Cadrage | Action | Textes à l'écran | Schéma 2D |
|---|---|---|---|---|---|
| 6.1 | 0-7,5 s | Spirale du bas (Saros), face arrière | crank 5,95 → 8,66, rapide. Les cases gravées calculées clignotent au passage de l'aiguille (la dernière est la case 107, Η) | « Saros : 223 mois » · « ≈ 18 ans 11 jours » · « Cycle babylonien » | (aucun) |
| 6.2 | 7,5-13 s | Même cadrage, plus serré sur l'aiguille | crank 8,66 → 8,98, lent. Les cases vides 108 à 111 défilent, puis l'aiguille entre dans la case 112 (à 8,975) et le signe « Σ Η » s'allume | « Case vide : pas d'éclipse » · « Σ = éclipse de Lune » · « Η = éclipse de Soleil » · en petit : « Signe calculé par notre modèle » | (aucun) |
| 6.3 | 13-17,5 s | Très gros plan sur le signe, puis panoramique vers le petit cadran Exeligmos | crank fixé. L'aiguille de l'Exeligmos est dans le secteur vide | « ΩΡ + chiffre = heure » · « Exeligmos : +0, +8, +16 h » · « Ici : +0 h » · « Lettre d'index → détails » | Anatomie d'un signe, marquée « exemple » : Σ, ΩΡ + chiffre, lettre d'index. La case 112 elle-même ne porte ni heure ni lettre (note 1) |
| 6.4 | 17,5-23,5 s | Coupe vers la face avant rapprochée | crank 8,98 → 9,014. La Lune vient se poser sur un bout de l'aiguille du Dragon, le Soleil est à l'autre bout ; l'aiguille s'illumine. La boule passe du noir au blanc | « Aiguille du Dragon : hypothèse » · « Dragon = nœuds de la Lune » · « Pleine lune sur le Dragon : éclipse possible » | (aucun) |
| 6.5 | 23,5-30 s | Schéma plein écran, puis retour sur la machine | La Lune traverse l'ombre de la Terre et s'assombrit | « Signes calculés par notre modèle » · « Possible · pas le lieu » | Géométrie d'une éclipse de Lune : Soleil, Terre, cône d'ombre, Lune |

## 7. Et la navigation ? (environ 38 s)

> Servait-elle à naviguer ? Non : ni viseur, ni latitude, ni longitude. C'est un calculateur du ciel. Mais regardez ces plaques : un calendrier des étoiles. Quand le Soleil atteint la lettre ksi, on lit : « La Pléiade se lève le matin. » Bien plus tard, pour Végèce, la mer est sûre après ce lever. Déjà Hésiode avertissait : quand les Pléiades « tombent dans la noire mer », rentre tes navires. La machine ne disait pas où aller, mais quand partir. La voici reconstruite, ses rapports prouvés mathématiquement, en accès libre. Et vous, quelle date allez-vous lui demander ?

| Plan | Durée | Cadrage | Action | Textes à l'écran | Schéma 2D |
|---|---|---|---|---|---|
| 7.1 | 0-6,5 s | Plan large de l'atelier (mode `wide`), trois-quarts avant, fenêtre ouverte sur le ciel et les collines (le décor actuel ne montre pas la mer ; pour la voir, ajouter une bande de mer dans `exterior_material()`) | crank fixé à 9,014 | « Pas un instrument de navigation » · « Ni viseur, ni latitude, ni longitude » · « Calculateur du ciel » | (aucun) |
| 7.2 | 6,5-16 s | Face avant, les deux plaques du parapegme surlignées | crank 9,014 → 9,13 (Soleil vers 47°, ΤΑΥΡΟΣ). Un Ξ en surimpression sur l'échelle du zodiaque, sous le Soleil. La ligne s'écrit en surimpression sur la plaque du haut | « Parapegme : calendrier des étoiles » · « Ξ : la Pléiade se lève » | (aucun) |
| 7.3 | 16-21 s | Schéma plein écran, puis bref retour sur l'anneau égyptien | Aube de mai : les Pléiades se lèvent à l'est avant le Soleil. Une barre de saison se remplit. Au retour, ΠΑΧΩΝ s'illumine sur l'anneau | « Végèce (IVe-Ve s. apr. J.-C.) » · « Mer sûre : 27 mai–14 sept. » · « ΠΑΧΩΝ : mois cité par Végèce » | Mer à l'aube, amas des Pléiades au-dessus de l'horizon est. Barre de saison (d'après Végèce) |
| 7.4 | 21-31 s | Schéma en incrustation sur la machine, puis retour plein cadre sur la machine à « La machine ne disait pas… » | crank 9,13 → 9,60 (Soleil vers 216°, ΣΚΟΡΠΙΟΣ). Dans le schéma, les Pléiades plongent dans une mer grise et ventée. Aucune ligne de parapegme n'est incrustée ici : le coucher des Pléiades n'est pas conservé sur la machine | « Hésiode, Les Travaux et les Jours » · « Fin oct.–début nov. : quitter la mer » · « Végèce : mer fermée du 11 nov. au 10 mars » · « Pas où aller : quand partir » | Pléiades se couchant dans la mer à l'aube, vagues |
| 7.5 | 31-35 s | Plan large de l'atelier au soleil, lente orbite de la caméra | explode 0 → 0,3 → 0 (la machine « respire »), la manivelle tourne doucement | « 69 roues · 30 conservées » · « Rapports prouvés (Lean 4) » · « Code et modèle libres · GitHub » · « taciclei » | (aucun) |
| 7.6 | 35-38 s | Carton final sur fond crème, la machine en fondu derrière | Les étapes apparaissent ensemble, puis la question | « 1. Tournez la manivelle » · « 2. Soleil : date, saison » · « 3. Lune : place, phase » · « 4. Planètes : place (hypothèse) » · « 5. Dos : mois, Jeux » · « 6. Signe : éclipse, heure » · « Et vous, quelle date ? » | (aucun) |

---

## Notes de réalisation

### Ce que le modèle ne montre pas encore (à compléter en 2D ou dans une copie de travail, jamais dans `am.blend`)

1. **Signes d'éclipse.** Dans la spec, la spirale du Saros n'a que des « placeholders ». Les signes affichés viennent de `glyphs.json` (`modele_epoque_t0`, règle `limits` : Σ si la pleine lune est à 10,8° au plus du nœud, Η si la nouvelle lune est à 17° au plus). C'est la table que lit aussi la page web ; la règle `freeth2014` donne les mêmes signes pour les cases 106 à 112. Case 112 : nouvelle lune à 8,976 (15,1° du nœud, donc Η) et pleine lune à 9,014 (0,5°, donc Σ). Le signe est donc « Σ Η » (Σ d'abord, comme sur l'original). La case 107 porte un Η, les cases 108 à 111 sont vides. Avant elles : 106 Σ, 101 Η, 100 Σ, 95 Η, 89 Η, 83 Σ Η, 77 Σ Η. **L'heure n'est pas calculée** : `glyphs.json` n'en donne pas, et elle n'aurait pas de sens tant que l'époque n'est pas calée. On n'écrit donc ni ΩΡ ni lettre d'index sur la case 112, et l'anatomie du plan 6.3 est un schéma marqué « exemple ».
2. **Cadran des Jeux.** Le modèle porte un seul nom par secteur (spec : ΙΣΘΜΙΑ, ΟΛΥΜΠΙΑ, ΝΕΜΕΑ, ΠΥΘΙΑ). Quand on tourne vers l'avant, on lit ΟΛΥΜΠΙΑ (an 1) → ΙΣΘΜΙΑ (an 2) → ΠΥΘΙΑ (an 3) → ΝΕΜΕΑ (an 4). Les ans 1, 3 et 4 portent bien une des deux fêtes historiques, mais l'an 2 est faux : l'original y porte Nemea et Naa, pas Isthmia. Comme le plan 5.3 passe sur ce secteur pendant que le bandeau affiche « An 2 : Nemea, Naa », il faut, dans la copie de travail, remplacer les quatre étiquettes par les paires historiques. Index 0 de la spec (an 2) : ΝΕΜΕΑ ΝΑΑ. Index 1 (an 1) : ΙΣΘΜΙΑ ΟΛΥΜΠΙΑ. Index 2 (an 4) : ΝΕΜΕΑ ΑΛΙΕΙΑ. Index 3 (an 3) : ΙΣΘΜΙΑ ΠΥΘΙΑ.
3. **Parapegme et lettres-repères.** Les plaques du modèle portent un texte provisoire, et l'échelle du zodiaque n'a pas de lettres. Le Ξ et la ligne « La Pléiade se lève le matin » sont donc des surimpressions. Leur position (Soleil vers 17° du Taureau, en écho au nombre 17 de la ligne Ξ) sert seulement d'illustration.
4. **Cases de Méton.** Elles ne portent pas de noms dans le modèle. L'incrustation « Phoinikaios… an 1 » est une illustration d'après Freeth et al. 2008.
5. **Soleil.** La sphère dorée (Soleil vrai, mécanisme hypothétique) et l'aiguille de date (Soleil moyen) s'écartent de 2,4° au plus. Au plan 3.2, on les surligne ensemble.
6. **Anneau égyptien.** Il était amovible dans l'original, mais il est fixe dans le modèle. Le film ne s'en sert pas pour lire une date historique.
7. **Fenêtre de l'atelier.** Le décor actuel (`exterior_material()`) montre un ciel et des collines, pas la mer. Le plan 7.1 s'en contente, sauf si l'on ajoute une bande de mer au décor.

### Mentions d'honnêteté obligatoires à l'écran

- Chap. 3 : « Sphère dorée : citée par l'inscription · son engrenage : hypothèse ».
- Chap. 4 : « Hypothèse · Freeth et al. 2021 » et « Couleurs modernes ».
- Chap. 6 : « Signe calculé par notre modèle » dès que le signe s'allume, « Aiguille du Dragon : hypothèse », « Signes calculés par notre modèle ». L'anatomie du signe est marquée « exemple ».
- Chap. 7 : « Pas un instrument de navigation ». Végèce est daté (IVe-Ve s. apr. J.-C.), donc bien après la machine, et la voix le dit (« Bien plus tard »). Hésiode et Végèce témoignent de la tradition des saisons de navigation : aucun des deux ne parle de la machine.
- À ne jamais écrire ni dire : « premier ordinateur », « construite par Archimède », « date exacte des Jeux », « découverte en 1901 ». L'épave a été trouvée en 1900 et la machine remarquée en 1902.
- Crédit : « taciclei », comme dans `LICENSE` et le README. Ne pas écrire de nom complet tant que l'auteur ne l'a pas donné.

### Prononciation (synthèse vocale)

Anticythère : « an-ti-si-tèr » · Végèce : « vé-jèss » · Hésiode : « é-zi-ode » · Pléiade : « plé-yade » · Saros : « sa-ross » · ksi : « ksi » · Sigma : « sig-ma » · Êta : « è-ta » · Olympia : « o-lin-pi-a ». Aucun mot grec n'est prononcé en dehors de Sigma, Êta, ksi et Olympia : les autres restent à l'écran.

### Sources par chapitre (fiche `faits.md`)

1. Découverte : WHOI, NAM, Jones 2020, Freeth et al. 2021.
2. Manivelle : guide de lecture, spec (223/48 tours de manivelle par an).
3. Face avant : Bitsakis & Jones 2016, Freeth et al. 2006, Freeth & Jones 2012, Freeth et al. 2021 (Soleil vrai hypothétique).
4. Planètes : Freeth & Jones 2012, Freeth et al. 2021.
5. Dos : Freeth et al. 2008 (+ SI), Iversen 2017, Jones 2020, NAM.
6. Éclipses : Freeth et al. 2008 SI, Freeth 2014, Freeth 2019. Signes : notre modèle (`glyphs.json`).
7. Navigation : Freeth et al. 2021, Jones 2017, Bitsakis & Jones 2016, Hésiode (trad. Leconte de Lisle), Végèce IV, 39. Preuves : README (193 théorèmes Lean 4).

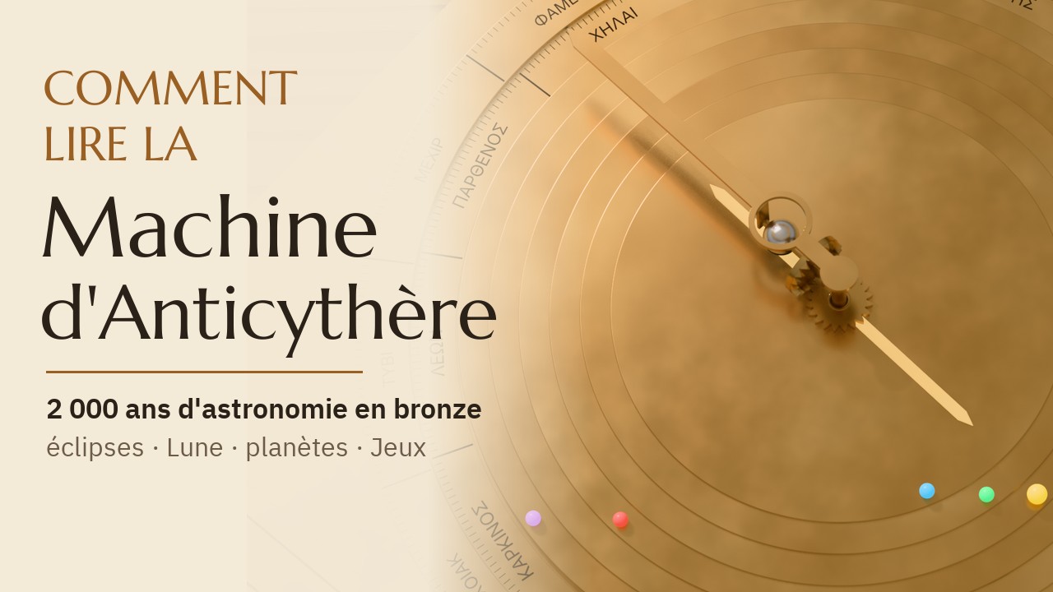
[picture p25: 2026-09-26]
build/out/explainer/publish/thumbnail.jpg

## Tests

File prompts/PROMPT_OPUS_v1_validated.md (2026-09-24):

# PROMPT MAÎTRE : mécanisme d'Anticythère fonctionnel dans Blender 5.2 (exécution en une seule fois)

> Donne ce prompt tel quel à une session Claude Code neuve (Opus 5.5), lancée dans un **dossier vide**.
> Il contient tout : mission, règles, décisions, formules, pièges connus et la spécification complète déjà
> vérifiée (§12). Aucune autre source n'est nécessaire, et internet n'est pas utilisé.

---

## 0. Mission

Dans le dossier courant, construis un projet qui :

1. charge la spécification JSON du §12, source de vérité unique ;
2. **démontre mathématiquement** en fractions exactes que chaque train d'engrenages reproduit son cycle
   astronomique et que le mécanisme a exactement **un degré de liberté** (la manivelle) ;
3. génère la géométrie 3D de toutes les pièces : 69 engrenages à développante conjugués, arbres, tubes,
   plaques, piliers, tenons-rainures, leviers suiveurs, cadrans avant et arrière, boîtier ;
4. assemble le tout dans **Blender 5.2** avec une manivelle unique qui anime chaque pièce par des drivers ;
5. **vérifie physiquement** qu'aucune pièce ne pénètre une autre sur toute la plage de mouvement ;
6. exporte les pièces pour l'impression 3D, rend des images et une animation, et produit un rapport de vérification.

Le travail est terminé lorsque **tous les livrables du §10 existent** et que chaque critère du §9 est **vert**, ou
marqué ROUGE avec son diagnostic selon la règle « Fin de session et priorités » du §1.

## 1. Règles de travail (non négociables)

- Travaille uniquement dans le dossier courant. Pas d'internet. N'installe rien (pas de pip, brew ni
  extension Blender). Ne modifie pas `/Applications/Blender.app`.
- **Ne pose aucune question** et n'attends aucune validation : tout est décidé ici. Si un détail n'est pas
  spécifié, choisis l'option la plus simple compatible avec la spec et note-la dans `DECISIONS.md`
  (une ligne : décision, raison).
- **La spec est intangible** : ne change aucune valeur. Si un contrôle échoue à cause d'une donnée de la
  spec, n'affaiblis pas le contrôle : applique le repli prévu au §8, sinon signale le problème en tête du rapport.
- N'affaiblis jamais un test ni une tolérance pour le faire passer. Seules les tolérances du §9 s'appliquent.
- Avance étape par étape (§7). À chaque point de contrôle, lance les commandes indiquées et corrige jusqu'au
  vert avant de continuer. Tiens `PROGRESS.md` à jour (étape, état, durée, problèmes et correctifs).
- Toute commande Blender tourne en arrière-plan avec un code de sortie :
  `"$BL" -b --factory-startup --python-exit-code 1 -P script.py -- args`. Journaux dans `out/logs/`.
- Une commande shell ne doit pas dépasser environ 9 minutes : découpe les rendus et les longues
  vérifications (plages de frames, lots d'échantillons), ou lance-les en arrière-plan et surveille leur fin.
- Le paquet `am/` n'importe **jamais** `bpy` ni `mathutils` : il doit être testable hors de Blender. Seuls
  les scripts de `blender_scripts/` touchent à Blender. Pas de dépendance hors bibliothèque standard et numpy.
- **Fin de session et priorités.** Si, après les replis du §8, un critère reste rouge à cause de la spec,
  marque-le ROUGE avec son diagnostic en tête du rapport et passe à l'étape suivante. La session se termine
  quand tous les livrables existent. Ordre de priorité si le temps manque : (1) étapes 0 à 3, (2) étapes 4
  et 5 avec `out/am.blend` animé, (3) rapport, (4) étape 6, (5) impression, (6) rendus Cycles, (7) animation.

## 2. Environnement (vérifié sur cette machine)

```sh
PY=/Applications/Blender.app/Contents/Resources/5.2/python/bin/python3.13   # 3.13.13, numpy 2.3.4, tomllib, fastjsonschema, unittest
BL=/Applications/Blender.app/Contents/MacOS/Blender                         # Blender 5.2.2 LTS
```

- N'utilise **jamais** `/usr/bin/python3` (3.9, sans numpy). Pas de scipy, pytest ni shapely.
- Mac Apple M4, 16 Go ; GPU Metal listé « Apple M4 (GPU - 8 cores) ».

## 3. Le mécanisme en bref (ce que modélise la spec)

- Une **manivelle** latérale tourne l'arbre `a` (axe horizontal +x). Sa couronne **a1** (48 dents) entraîne la
  grande roue **b1** (223 dents) : **1 tour de b1 = 1 année**. Toutes les vitesses sont en tours par an.
- **Trains arrière**, derrière la plaque principale :
  - **Lune** : b2→c→d→e2/e5→k1, puis un **tenon-rainure** k1⇢k2 porté par le plateau tournant **e3**, puis
    k2→e6/e1→b3. Le résultat est la Lune moyenne 254/19 plus l'anomalie d'Hipparque.
  - **Métonique / Olympiade / Callippique** : b2→l→m→n→(o, p→cal).
  - **Saros / Exeligmos** : m3→e3/e4→f→g→h→i.
  - Les deux chemins partis de b2 se rejoignent sur e3 : c'est un vrai différentiel.
- **Trains avant** (modèle Freeth 2021, en grande partie **hypothétiques**) :
  - sur b1 : nœuds (main du dragon), Mercure et Vénus. Ce sont des épicycles portés par b1 qui engrènent
    des roues fixes. Un tenon sur chaque épicycle entraîne un **levier suiveur** monté sur l'axe central ;
  - sur la plaque **CP**, qui tourne avec b1 : Soleil vrai (excentrique + levier) et planètes supérieures
    (Mars, Jupiter, Saturne), chacune avec un tenon-rainure et une roue de sortie sur l'axe central.
- **Sorties** :
  - à l'avant, des tubes concentriques portent des anneaux planétaires, l'aiguille lunaire avec sa sphère
    de phase (différentiel b0/q1), l'aiguille de date et la main du dragon ;
  - à l'arrière, deux spirales (Métonique 5 tours / 235 cases, Saros 4 tours / 223 cases) suivies par des
    aiguilles à coulisseau, plus trois cadrans secondaires.
- Chaque pièce a un **statut** : `SURVIVING`, `RECONSTRUCTED` ou `HYPOTHETICAL`. Il est conservé partout :
  propriétés, collections, couleurs de débogage, rapport.

## 4. Décisions déjà tranchées (ne pas les rediscuter)

1. **Unités** : 1 unité Blender = 1 mm (`unit_settings.system='METRIC'`, `length_unit='MILLIMETERS'`,
   `scale_length=0.001`). `scale_length` est stocké en float32 : compare avec `math.isclose(x, 0.001, rel_tol=1e-6)`,
   jamais `==`. Caméras : `clip_start = 1.0`, `clip_end = 10000.0`. Repère et signes : voir `conventions` dans la
   spec. Taux positif = sens horaire vu de face.
2. **Profil de dent** : développante à **30°**, saillie 1·m, creux 1,25·m, congé de pied 0,2·m, sans
   déport. Jeu **uniquement par amincissement des dents** (0,03 mm pour le modèle savant), **jamais** en
   déplaçant les axes. Modules, positions d'axes et plages Z : ceux de la spec, sans modification.
3. **Couronnes** a1/b1 et b0/q1 : dents **déjà calculées par enveloppe** et vérifiées (spec `crowns`), à
   construire telles quelles (§5.6).
4. **Mouvement** : un Empty `AM_Controller` porte `ctl['crank'] = 0.0` (années) et `ctl['patina'] = 0.0`,
   écrits en **littéraux flottants** : avec `= 0`, la propriété serait entière et l'animation sauterait par
   années entières. Vérifie `type(ctl['crank']) is float` avant `keyframe_insert`, et applique
   `ctl.id_properties_ui('patina').update(min=0.0, max=1.0)`. Chaque corps est un Empty `B_<id>` dont la
   rotation est pilotée par un driver en **expression simple** : pas de fonction Python, pour que le fichier
   s'anime sans autorisation de scripts. **Pas de physique rigide** (Bullet) : elle ne peut pas reproduire
   des rapports exacts.
5. **Hiérarchie** : chaque pièce est un objet enfant de l'Empty de son corps, modélisé en coordonnées
   locales du corps. Les corps dont le parent est `b` ou `e_table` sont enfants de `B_b` ou de
   `B_e_table`. `matrix_parent_inverse` est l'identité partout. La position de l'Empty vaut
   `axis_xy_in_parent` dans le repère du parent. Tous les Empties sont à z = 0, sauf `B_a` (z = axe de a1)
   et `B_q` (z = 52,70 dans `B_moon`).
6. **Collections** : `AM_SURVIVING`, `AM_RECONSTRUCTED`, `AM_HYPOTHETICAL` pour les engrenages et pièces
   à statut ; `AM_STRUCTURE`, `AM_DIALS`, `AM_CASE`, `AM_HELPERS` (Empties). Propriétés personnalisées sur
   chaque objet : `status`, `role`, `teeth`, `module`, `body`, `sources`.
7. **Matériaux** : bronze PBR avec un mélange de patine piloté par `AM_Controller["patina"]` (0 = neuf,
   1 = musée), bois pour le boîtier. `obj.color` = couleur de statut, pour un affichage de débogage en
   Solid/Object.
8. **Incertitudes** : on applique les valeurs par défaut de la spec (`unresolved_defaults`). Le rapport les liste.

## 5. Formules (exactes, à implémenter telles quelles)

### 5.1 Angles et taux
- Angle d'un corps (convention mathématique, sens trigonométrique autour de son axe, relatif à son parent) :
  **θ(t) = −2π · rate_rel_parent · t** pour un corps linéaire, t en années.
- **Willis**, pour un engrènement extérieur de g1 (corps B1) et g2 (corps B2) sur le porteur C :
  z1·(w1 − wC) = −z2·(w2 − wC).
- Le solveur `am/kinematics.py` reconstruit **tous** les taux moyens par élimination de Gauss exacte
  (`fractions.Fraction`) :
  - inconnues : les **45 corps mobiles** hors `frame`, `a` et `q` ;
  - **44 équations** : 37 engrènements extérieurs (Willis), 4 tenons-rainures (taux moyen de la roue à rainure
    = taux moyen de la roue à tenon), 3 suiveurs (taux moyen du suiveur = taux de `b`, car d < i) ;
  - entrée : taux de `b` = 1.
  Il doit trouver : rang 44 (**DDL = 1**), aucune contrainte incohérente, des taux égaux à
  `bodies[].rate_abs_mean`, et **toutes** les `targets`. Deux cibles sont hors solveur et comparées en valeur
  absolue : `a` = 223/48 (définition) et `q@moon` = |w_b − w_moon| = 235/19.

### 5.2 Angles de chaque corps (à utiliser pour les drivers et le solveur)
| corps | parent | axe (repère du parent, mm) | roues | taux moyen absolu | angle θ(t) |
|---|---|---|---|---|---|
| `frame` | — | — | fx51, fx49, fx56 | 0 | fixe |
| `a` | frame | (0.0000, 0.0000) | a1 | — | autour de +x : −2π·(223/48)·t |
| `b` | frame | (0.0000, 0.0000) | b1, b2, b0 | 1 | −2π·(1)·t |
| `moon` | frame | (0.0000, 0.0000) | b3 | 254/19 | monde : θ = −θ_e_inner |
| `c` | frame | (-7.8891, -23.1740) | c2, c1 | -32/19 | −2π·(-32/19)·t |
| `d` | frame | (-13.0733, -38.4156) | d1, d2 | 64/19 | −2π·(64/19)·t |
| `e_pipe` | frame | (14.1105, -11.0151) | e2, e5 | -254/19 | −2π·(-254/19)·t |
| `e_table` | frame | (14.1105, -11.0151) | e3, e4 | -477/4237 | −2π·(-477/4237)·t |
| `e_inner` | frame | (14.1105, -11.0151) | e1, e6 | -254/19 | monde : θ = θ_e_table − θ_kp (θ_kp local à e_table) |
| `k` | e_table | (20.1731, -15.7609) | k1 | 55688/4237 | −2π·(56165/4237)·t (local) |
| `kp` | e_table | (21.0399, -16.4382) | k2 | 55688/4237 | tenon-rainure : θ = θ_k + atan2(1.1·sin(θ_k − β), 9.6 − 1.1·cos(θ_k − β)), β = −38° |
| `l` | frame | (19.8733, 14.2941) | l2, l1 | -32/19 | −2π·(-32/19)·t |
| `m` | frame | (0.0000, 45.5000) | m1, m3, m2 | 53/57 | −2π·(53/57)·t |
| `f` | frame | (19.7179, -73.4600) | f1, f2 | 1692/4237 | −2π·(1692/4237)·t |
| `g` | frame | (0.0000, -82.5240) | g1, g2 | -940/4237 | −2π·(-940/4237)·t |
| `h` | frame | (11.5059, -96.2362) | h1, h2 | 940/12711 | −2π·(940/12711)·t |
| `i` | frame | (-0.2562, -107.5227) | i1 | -235/12711 | −2π·(-235/12711)·t |
| `n` | frame | (0.0000, 62.9760) | n1, n3, n2 | -5/19 | −2π·(-5/19)·t |
| `o` | frame | (-24.4003, 62.9760) | o1 | 1/4 | −2π·(1/4)·t |
| `p` | frame | (12.7650, 76.7098) | p1, p2 | 5/76 | −2π·(5/76)·t |
| `cal` | frame | (24.4003, 62.9760) | cal1 | -1/76 | −2π·(-1/76)·t |
| `q` | moon | (0.0000, 0.0000) | q1 | — | autour de son X local (radial), relatif à `moon` : θ_q = θ_b − θ_moon (NON LINÉAIRE ; moyenne +235/19) |
| `spA` | b | (16.5726, 28.7046) | me72, me89 | 41/24 | −2π·(17/24)·t (local) |
| `spB` | b | (23.3827, -13.5000) | nd62, nd64 | 111/62 | −2π·(49/62)·t (local) |
| `spC` | b | (-12.8000, -22.1703) | vn44, vn34 | 95/44 | −2π·(51/44)·t (local) |
| `x_me40` | b | (28.2742, -1.3476) | me40 | -553/960 | −2π·(-1513/960)·t (local) |
| `x_me20` | b | (32.3566, -15.7814) | me20 | 1993/480 | −2π·(1513/480)·t (local) |
| `x_vn26` | b | (-11.0705, -6.6362) | vn26 | -295/572 | −2π·(-867/572)·t (local) |
| `x_r1` | b | (-25.1954, 11.7488) | r1 | 751/462 | −2π·(289/462)·t (local) |
| `t_nodes` | frame | (0.0000, 0.0000) | nd48 | -5/93 | −2π·(-5/93)·t |
| `x_cp52` | b | (-8.8652, 24.3568) | cp52, sa61 | 27/13 | −2π·(14/13)·t (local) |
| `x_cp64` | b | (2.5101, -28.6904) | cp64, ma38, ju45 | 15/8 | −2π·(7/8)·t (local) |
| `x_su56` | b | (-34.3914, 19.8559) | su56 | 0 | −2π·(-1)·t (local) |
| `x_sa40` | b | (-1.0611, 47.3062) | sa40 | -167/260 | −2π·(-427/260)·t (local) |
| `x_sa68` | b | (22.1400, 35.7495) | sa68 | 869/442 | −2π·(427/442)·t (local) |
| `x_sa86s` | b | (20.6400, 35.7495) | sa86s | 869/442 | tenon-rainure : θ = θ_x_sa68 + atan2(1.5·sin(θ_x_sa68 − β), 14.37 − 1.5·cos(θ_x_sa68 − β)), β = 180° (local à b) |
| `x_ju40` | b | (22.0874, -34.4253) | ju40 | 1/64 | −2π·(-63/64)·t (local) |
| `x_ju43` | b | (28.6000, -15.6000) | ju43 | 659/344 | −2π·(315/344)·t (local) |
| `x_ju65s` | b | (27.0200, -15.6000) | ju65s | 659/344 | tenon-rainure : θ = θ_x_ju43 + atan2(1.58·sin(θ_x_ju43 − β), 8.22 − 1.58·cos(θ_x_ju43 − β)), β = 180° (local à b) |
| `x_ma40` | b | (-3.8512, -46.2964) | ma40 | 27/160 | −2π·(-133/160)·t (local) |
| `x_ma71` | b | (-24.8984, -29.9654) | ma71 | 417/284 | −2π·(133/284)·t (local) |
| `x_ma80s` | b | (-19.2000, -33.2554) | ma80s | 417/284 | tenon-rainure : θ = θ_x_ma71 + atan2(6.58·sin(θ_x_ma71 − β), 10.0 − 6.58·cos(θ_x_ma71 − β)), β = 330° (local à b) |
| `t_saturn` | frame | (0.0000, 0.0000) | sa86o | 15/442 | monde : θ = θ_b − θ_x_sa86s (θ_x_sa86s local à b) |
| `t_jupiter` | frame | (0.0000, 0.0000) | ju65o | 29/344 | monde : θ = θ_b − θ_x_ju65s (θ_x_ju65s local à b) |
| `t_mars` | frame | (0.0000, 0.0000) | ma80o | 151/284 | monde : θ = θ_b − θ_x_ma80s (θ_x_ma80s local à b) |
| `t_mercury` | frame | (0.0000, 0.0000) | — | 1 | suiveur : θ = θ_b + γ0 + atan2(d·sin λ, i + d·cos λ), λ = θ_x_me20 − γ0 ; i = 36.0000, d = 14.0400, γ0 = -26.0000° |
| `t_venus` | frame | (0.0000, 0.0000) | — | 1 | suiveur : θ = θ_b + γ0 + atan2(d·sin λ, i + d·cos λ), λ = θ_x_r1 − γ0 ; i = 27.8000, d = 20.0100, γ0 = 155.0000° |
| `t_trueSun` | frame | (0.0000, 0.0000) | — | 1 | suiveur : θ = θ_b + γ0 + atan2(d·sin λ, i + d·cos λ), λ = θ_x_su56 + 84.5° − γ0 ; i = 39.7117, d = 1.6547, γ0 = 150.0000° |

Détails :
- **Tenon-rainure** : θ_rainure = θ_tenon + atan2(e·sin(θ_tenon − β), r − e·cos(θ_tenon − β)). Les angles
  sont relatifs au porteur ; e = excentricité, r = rayon du tenon, β = `offset_dir_local_deg` en radians. La
  fonction est continue car e < r, et son taux moyen égale celui du tenon.
- **Suiveur** : θ_F = θ_b + γ0 + atan2(d·sin λ, i + d·cos λ), avec γ0 = atan2 de `epicycle_axis_xy_in_b`
  (λ : voir ci-dessous). Le levier (local +x) pointe alors toujours vers le tenon.
- **Phase lunaire** : `B_q` tourne autour de son X local (radial, le long de l'aiguille lunaire), par rapport
  à `B_moon`, de **θ_q = θ_b − θ_moon**, avec les angles monde en z. Loi **non linéaire**, car la Lune porte
  l'anomalie ; taux moyen +235/19 ; θ_q(0) = −0,0773916 rad. Driver : `-2*pi*fmod(c,1) - m`, où `m` est une
  variable `SINGLE_PROP` sur `B_moon.rotation_euler[2]`. N'utilise **jamais** la forme linéaire : les dents de
  q1 dériveraient jusqu'à 11° contre celles de b0.
- **Manivelle** : `B_a` tourne autour de X : **−2π·(223/48)·t**.
- Les valeurs du tableau sont arrondies pour la lecture. **Toutes les constantes** (axes, i, d, γ0, e, r, β,
  phases des tenons) se lisent dans le JSON en float64.
- **Suiveur (précision)** : λ = θ_épicycle_local + φ_t − γ0, avec φ_t = `followers[].pin_phase_deg` en
  radians (0 pour Mercure et Vénus, 84,5° pour le Soleil vrai). Le tenon est à l'angle local φ_t de son épicycle.
- Dans les drivers, garde les angles petits : `fmod(c*N/D, 1)` avant de multiplier par 2π, avec des fractions
  entières exactes. Pour composer un corps non linéaire, lis la rotation locale d'un autre Empty par une
  variable `SINGLE_PROP` sur `rotation_euler[2]` (ou `[0]` pour les axes X). Ne réinjecte **jamais** un angle
  modulé dans un rapport : les rapports utilisent toujours `c`.

### 5.3 Phasage des dents au montage
Pour chaque engrènement extérieur, calculé à t = 0 avec les angles réels des corps (non nuls pour les corps
non linéaires) : soit β12 l'angle de la ligne des centres de l'axe 1 vers l'axe 2 dans le repère du porteur,
φ1 l'angle monde de la dent 0 de g1 (angle du corps + décalage de phase de g1). Alors la dent 0 de g2 doit être
à φ2 = β12 + π + π/z2 − (z1/z2)·(φ1 − β12). Intègre ce décalage de phase dans le maillage de g2. Le graphe
des engrènements extérieurs a 28 composantes (b1 n'engrène que la couronne a1). Dans chacune, donne la phase 0
à une roue racine (la première roue de la composante rencontrée dans `meshes`), puis propage le long de
l'arbre. Deux roues d'un même corps ont des décalages indépendants. Vérifie ensuite chaque paire par le contrôle 2D du §5.8. Les couronnes a1 et q1 sont **déjà
phasées** dans leurs grilles d'enveloppe : la dent 0 est centrée en φ = π/48 (a1) ou π/20 (q1), face à la dent
0 de b1 ou b0, quand l'angle relatif est nul (a1 : θ_a = 0 ; q1 : θ_q = θ_b − θ_moon = 0). Construis les dents aux
φ de la grille **sans aucun décalage**. À t = 0, θ_q(0) = −0,0774 rad est porté par la rotation de `B_q`, et la
dent 0 de b0 est au même angle dans le repère Lune. b1 et b0 gardent leur dent 0 à l'angle local 0.

### 5.4 Profil à développante (numpy, float64)
r = m·z/2 ; rb = r·cos α ; ra = r + m ; rf = r − 1,25·m ; inv(x) = tan x − x.
Demi-angle de dent au rayon ρ ≥ rb : ψ(ρ) = π/(2z) + inv(α) − inv(arccos(rb/ρ)) − j/(4r), où j est le jeu
circonférentiel. Flancs de la dent k (centre θk = 2πk/z + phase) : ρ·(cos(θk ± ψ(ρ)), sin(θk ± ψ(ρ))), avec
ρ de max(rb, rf) à ra, **au moins 24 points par flanc**. Si rf < rb (z < 19 à 30°), prolonge radialement
de rb à rf. Arc de tête à ra, arc de pied à rf, congé ≈ 0,2·m. Retire les points consécutifs confondus
(tolérance 1e-9) : `me.validate()` ne les fusionne pas.
- **Largeur en tête** (`tooth.tip_land_rule`) : ≥ 0,2·m sur le profil **nominal** (j = 0) ; sur les profils
  amincis, > 0, valeur seulement rapportée.
- **Évidements** : suis exactement `tooth.lightening`. Pas de fenêtres pour les roues à tenon ou à rainure ;
  e3 a un bras vers K ; pour **b1**, les 4 rayons A/B/C/D de `b1_structure` ; **e4** est un anneau.
- **Alésage** de chaque roue : `gears[].bore_radius`. Une roue `fused` fait partie du corps de son arbre ; une
  roue `rides_on` tourne sur un support d'un autre corps avec 0,05 mm de jeu. Arbres, goujons, bossages, moyeux
  et tenons : exactement la table `shafts` (rayons et plages Z).
- **Cercles avec jeu** (alésages, trous, goujons, bossages, tubes) : polygones de
  n ≥ max(64, ⌈π/acos(R/(R+g))⌉ + 8) côtés, avec le même n pour l'alésage et l'arbre.

### 5.5 Maillages dans Blender
Extrude les contours 2D (extérieur + trous) entre z0 et z1. Triangule chaque face plane avec
`mathutils.geometry.delaunay_2d_cdt(pts2d, [], [boucle_ext, trou1, …], 3, 1e-9)` (output_type 3 : triangles
intérieurs, trous retirés). **N'utilise pas `tessellate_polygon`**, faux sur ces contours (§11). Contrôle : aucun
sommet ajouté (sinon le contour se recoupe : corrige-le), n + 2·(nombre de trous) − 2 triangles, aucune arête
partagée par plus de 2 triangles. Remplis ensuite `vertices`, `loops` et `polygons` avec `foreach_set` (pas de
`from_pydata` ni de bmesh dent par dent). Ensuite `me.validate()`,
`me.shade_smooth()`, `me.set_sharp_from_angle(angle=radians(30))`. **Orientation** : le contour extérieur en
sens trigonométrique, chaque trou en sens horaire (aire signée), parois générées dans ce sens. Chaque maillage
doit être **fermé, variété, orienté de façon cohérente** : aucune arête bmesh avec
`is_manifold and not is_contiguous`. Son volume, calculé en float64 sur les sommets relus, doit valoir
aire du contour × (float32(z1) − float32(z0)) à 1e-6 près (relatif), avec float32(z) = `float(numpy.float32(z))`
(les sommets sont stockés en float32). Pas de modificateur booléen sur la géométrie vérifiée.

### 5.6 Couronnes (contrates) : dents précalculées par enveloppe
Les dents de a1 et q1 sont **fournies** dans `crowns.a1.envelope` et `crowns.q1.envelope`. Ce sont des grilles
(s, ρ, φ_lo, φ_hi) calculées comme la région que les dents de b1 ou b0 (jeu 0,03 et marge 0,04 par flanc) ne
balaient jamais. Elles ont été vérifiées dans Blender 5.2.2 : **0 recouvrement BVH** sur 60 positions par pas, et
un jeu minimal de 0,013 à 0,041 mm à chaque position, donc un engrènement continu. **Ne les recalcule pas.**
Construis chaque dent selon `crowns.mesh_rule`, répète-la z fois (φ += k·2π/z), et ajoute le disque, l'arbre, la
manivelle (a1), l'arbre radial, les supports et la sphère de phase (q1) aux cotes du bloc `crowns`. Les dents
pénètrent le disque de 0,05 mm : ce sont des coques fermées séparées dans le même objet (même corps), et le
contrôle de variété se fait par coque. Repères : a1, s = x monde et φ autour de +x depuis −z vers +y ; q1, s = u
du repère Lune et φ autour de +u depuis −z vers +v.

### 5.7 Spirales arrière et coulisseaux
Repère arrière (u, v) = (−x, y). ψ = angle du corps n (Métonique) ou g (Saros), positif = sens horaire vu de
l'arrière = +θ en convention monde. On a k = floor(ψ/2π), φ = ψ − 2πk, R_k = r_start + k·pitch,
δ = pitch/2. Si φ < π, ρ = R_k. Sinon ρ = δ·cos φ + sqrt((R_k + δ)² − δ²·sin²φ). Le deuxième centre est au
centre du cadran + (0, +δ) en (u, v). La rainure (largeur 1,2) est taillée dans la plaque arrière le long de
cette spirale, pour ψ de 0 à tours·2π, avec des **extrémités rondes** (r 0,6) centrées sur les points
ψ = 0 et ψ = tours·2π. Les cases sont des traits radiaux entre les tours : 47 par tour pour le Métonique, 223
sur 4 tours pour le Saros. Le coulisseau (tenon r 0,5, appartenant au corps n ou g de son aiguille) glisse le
long du +y local de l'aiguille. Sa position `location.y` est pilotée par un driver qui calcule ψ_mod
**directement depuis c**, jamais depuis la rotation modulée de l'aiguille :
- Métonique : `10*pi*fmod(fmod(c/19,1)+1,1)` ;
- Saros : `8*pi*fmod(fmod(c*235/4237,1)+1,1)`.
La F-curve de ce driver est une **table de correspondance** ψ→ρ : ≥ 1800 clés, interpolation LINEAR. Vide
d'abord les 2 clés par défaut avec `fc.keyframe_points.clear()`.
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

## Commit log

2026-09-24 Antikythera Mechanism: functional, verified 3D reconstruction in Blender 5.2
    - 69 gears with real tooth counts, conjugate 30-degree involute teeth,
    envelope-generated crown gears, exact kinematics (1 DOF, 22 exact targets)
    - single-source spec (spec/antikythera.json) with generator and independent
    validators; master prompt that rebuilt everything in one pass (prompts/)
    - one-pass build (build/): Python package, Blender scripts, tests, report,
    am.blend, 3 print profiles, renders and the main video
    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
    [a1.stl, a_shaft.stl, am.blend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]
2026-09-24 Update README with user attachment links
    Added links to user attachment assets in the README.
2026-09-24 Add the exploded-view video and museum-lit Cycles stills
    - build/out/renders/antikythera_eclate.mp4 (360 frames, exploded view with orbiting camera)
    - stills and README images re-rendered with the museum staging; the exploded still now
    uses the explode slider so labels and legend move with their parts
    - render_staged.py: stills 'exploded' go through AM_Controller['explode']
2026-09-25 Formal proofs in Lean 4 (193 theorems, Mathlib)
    - lean/: Lean 4 + Mathlib project, checked with warnings as errors.
    - Kinematics, Targets, Geometry: generated from the spec by tools/make_lean.py.
    - one degree of freedom for the mean rates, every rate determined by the crank;
    - the 22 astronomical targets from the tooth counts alone;
    - 37 centre distances within 1e-6 mm.
    - PinSlot: the nonlinear pin-and-slot and follower laws.
    - exact maximal deviation arcsin(e/r), smooth and monotone motion;
    - mean rates unchanged, which formally justifies the linear fields of Kinematics;
    - lunar anomaly amplitude between 6.579 and 6.581 degrees.
    - Astronomy: the Metonic, Saros,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
2026-09-25 CI: check the Lean proofs on every change
    Regenerates Kinematics/Targets/Geometry from the spec and fails if they differ from the committed files,
    then builds the Lean project with lean-action (Mathlib cache, warnings as errors, axiom audit).
2026-09-26 Explainer: how to read the machine (film, interactive page, astronomy engine)
    - Explainer film « Le ciel dans une boîte : comment lire la machine d'Anticythère » (French, 2 min 40 s,
    https://youtu.be/eXvYkouJy_w):
    - 7 chapters, daylight workshop look;
    - local French voice-over (Mistral Voxtral TTS, fr_female; weights CC BY-NC 4.0, so non-commercial);
    - burned-in subtitles.
    The pipeline is in tools/explainer/film/:
    - timeline tied to the words of the narration, with its beats checked against the engine;
    - build_film.py, anchors, resumable EEVEE renderer;
    - compositor (callouts, counter, inserts) and encoder.
    - Interactive page docs/lire/ (GitHub Pages): set a date, turn th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
    [am.blend, am_atelier.blend]
2026-10-04 Anticythère 2.0: design study and verified architecture (v2/)
    A modern evolution of the mechanism, kept apart from the historical v1:
    - research: modern constants, mechanism choices, historical precedents
    - spec/trains.json: 70 shafts, exact gear ratios, 65 checks
    - spec/architecture.json: wheel-by-wheel placement of 13 trains,
    368+ parts with z ranges, 0 collisions, exact-id links
    - study: trains.md, architecture.md (version 4), figures, etude.html
    - three adversarial reviews (review.md, review2.md, review3.md) and
    the fixes they led to
    - docs/v2/: the study page for GitHub Pages
    [nasa_lunar_eclipses_2001_2100.csv, nasa_solar_eclipses_2001_2100.csv]
2026-10-04 Anticythère 2.0: Blender model, Lean proofs and 3D section of the study (v2/)
    - v2/blender: 415-part model built from spec/scene.json (true involute gears,
    crown and bevel contacts, drilled plates, translucent blocks), front/back/lid
    faces, case and crank; animation driven by V2_Controleur["jours"] with exact
    train rates and ephemeris-baked outputs. check.py: 477 valid meshes,
    133 meshing contacts x 24 samples with 0 overlaps, 183 static pairs with
    0 collisions. EEVEE renders and a one-year animation.
    - v2/tools: scene_model.py (architecture -> scene.json), ephem.py (validated
    against JPL Horizons 2000-2100), make_lean_v2.py + lean_v2/, mutation test.
    - v2/lean: 201 generated th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
2026-10-04 Anticythère 2.0: Lean proofs of the nonlinear mechanisms, Blender side of the Kepler towers
    - v2/lean/AnticythereV2/Mechanisms.lean (hand-written, 48 theorems): vector-module
    identity (outer and inner), heliocentric pivot, two-arm ellipse and focal distance,
    Kepler's equation (strictly monotone, unique solution, resolver loop, no dead
    point), bisected-equant pin uniqueness, Oldham coupling (same rotation by
    continuity), Hooke joint and right ascension. The generator reads it without
    rewriting it (tools/lean_v2/hand.py rejects sorry/axiom/set_option); Audit checks
    each theorem by name. 249 theorems, standard axioms only.
    - v2/blender: kepler_build/kepler_geom/kepler_check build t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
